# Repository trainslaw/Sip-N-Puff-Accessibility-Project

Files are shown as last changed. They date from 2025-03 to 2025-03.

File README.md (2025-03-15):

# 🧠 Sip-and-Puff Mouse Emulator — Affordable, Open-Source Accessibility Device

## ✨ About the Project

The **Sip-and-Puff Mouse Emulator** is a **low-cost, open-source accessibility device** that allows users who cannot use their hands to control a computer mouse with simple "sip" and "puff" actions, plus an additional bottom lip button for customizeable actions (preset to be middle click for easy scrolling). 

While commercial sip-and-puff systems can cost **upwards of $1,500**, this device is designed to be **DIY-friendly**, **3D printable**, and assembled for **a fraction of the price** — **typically under $85** in materials.

If you or someone you know needs this kind of assistive technology but can't afford commercial versions, **this project is for you**. 

---

## 💡 Features

- **Sip and Puff** for right and left mouse clicks (supports click and drag).
- Optional **joystick module** for directional control (mouse movement).
- **3D printable** housing — fully open-source design.
- **Standard 1/4" tripod mount** on the bottom for flexible positioning (desk mount, wheelchair, etc.).
- Uses **readily available parts** and standard **Arduino Micro**.
- Open-source **Arduino firmware** for customization and improvements.

---

## 📦 Bill of Materials (BOM)

| Component | Quantity | Approx. Cost (USD) |
|---|---|---|
| HiLetgo Digital Barometric Pressure Sensor Module (0-40KPa) | 1 | $3.00 |
| Arduino Micro (or Pro Micro compatible) | 1 | $22.10 |
| Standard joystick module (optional) | 1 | $5.00 |
| M3 x 5mm heat-set threaded inserts | 12 | $8.00 (pack of 50)|
| M3 x 6mm screws | 12 | $6.00 (pack of 100)|
| M2 x 5mm screws | Few | $5.00 (pack of 100)|
| 1/4" threaded insert (tripod mount) | 1 | $1.50 |
| Female-to-female jumper wires | — | $7.00 (pack of 40)|
| 2.5mm ID surgical tubing | ~1 ft | $5.00 |
| PLA filament (3D printing) | ~100g | $20.00 (1kg spool)|

> **Note**: Prices are estimates and may vary depending on supplier and shipping. Total estimated cost: **~$82.60**

---

## 🖨️ 3D Printing

The 3D-printable case is designed to be easily assembled and maintained:
- **Material**: PLA (can use one or multiple colors).
- **Threaded inserts** for strong, durable screw connections.
- **1/4" threaded mount** in base for positioning.

Find STL files in `/3D_Models/printFiles`.

---

## ⚙️ Assembly Guide

🛠️ **Detailed step-by-step assembly instructions** can be found in `/Documentation/Assembly_Guide.md`.  
This includes:
- 3D printing recommendations.
- Sensor, tubing, and electronics installation.
- Wiring diagrams for connecting the Arduino and sensors.
- Firmware upload guide for Arduino Micro.

---

## 💨 How It Works

- **"Puff" action** triggers a left mouse click.
- **"Sip" action** triggers a right mouse click.
- **Bottom Lip Button** triggers a middle click (for easy scrolling).
- **Joystick Functionality** moves the mouse cursor (analog control).

The device uses a **barometric pressure sensor** to detect airflow changes in the attached surgical tubing. Arduino firmware interprets these signals and emulates mouse input via USB.

---

## 🖥️ Usage and Setup

1. **Connect** the device to your computer using a USB cable.
2. **Sip and puff** to generate clicks.
3. Use the **joystick** for cursor movement.
4. **Adjust mount position** as needed for comfort.

---

## 🧑‍💻 Firmware and Customization

The Arduino sketch is available in `/SipNPuff.ino`.  
You can:
- **Adjust pressure thresholds** for sip and puff in the code.
- Modify click/hold behavior.
- Customize joystick sensitivity.

Upload using **Arduino IDE** — instructions included in `/Documentation`.

---

## 🔓 License

This project is licensed under the **Creative Commons Attribution-ShareAlike 4.0 International (CC BY-SA 4.0)**.

> You are free to share, adapt, and build upon this work — even commercially — as long as you **attribute** the original creator and **share alike** under the same license.  
> See the full license [here](https://creativecommons.org/licenses/by-sa/4.0/).

---

## 🤝 Contributing

Contributions are welcome!  
If you improve the design, firmware, or create alternative versions, **please submit a pull request** or open an issue to share your work with the community.

---

## 📣 How to Share and Help

If you build this device or know someone who could benefit from it:
- Share this repo.
- Post about it on social media (tag me if you like! Instagram: @trainslaw24).
- Help improve it for others — **collaboration makes this stronger**.

---

## 📫 Contact

For questions, feedback, or collaboration, feel free to reach out via GitHub issues.

---

## 🔗 Related Links

- [Creative Commons License Info](https://creativecommons.org/licenses/by-sa/4.0/)
- [Instructables Guide (coming soon!)](https://www.instructables.com/)
- [3D Model Repository (Thingiverse Link)](https://www.thingiverse.com/thing:6980375)
- [Testing Video](https://youtu.be/Zvc_8lLqynY)

---

### Created by [trainslaw](https://github.com/trainslaw)

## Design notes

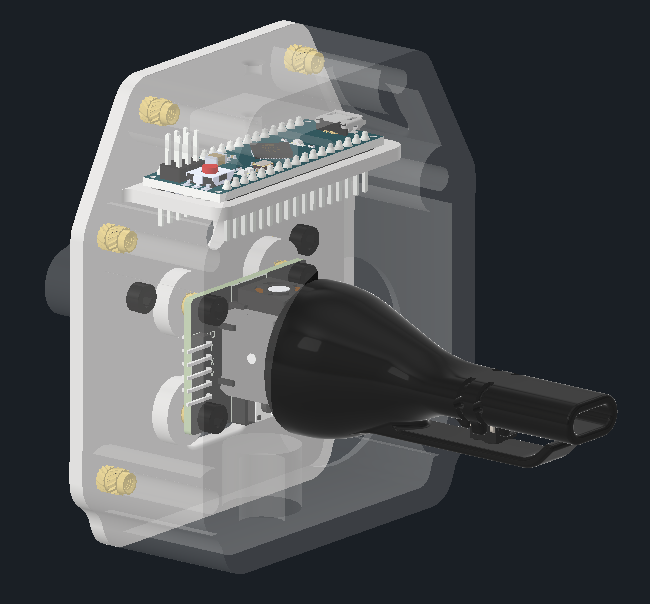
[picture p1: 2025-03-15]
Screenshot 2025-03-14 161028.png

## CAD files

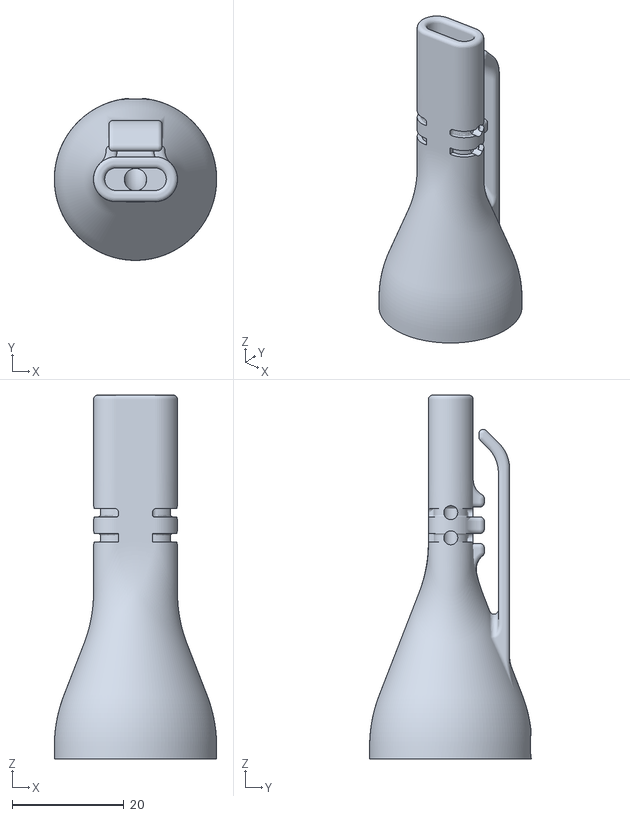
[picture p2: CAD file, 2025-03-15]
3D_Models/Print Files/mouthpiece.stl
29.0 x 28.9 x 65.0

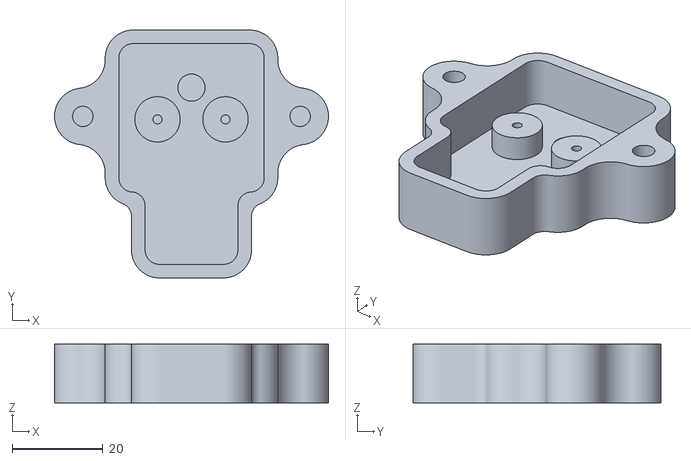
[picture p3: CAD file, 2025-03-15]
3D_Models/Print Files/pressure_housing.stl
60.5 x 54.7 x 13.0

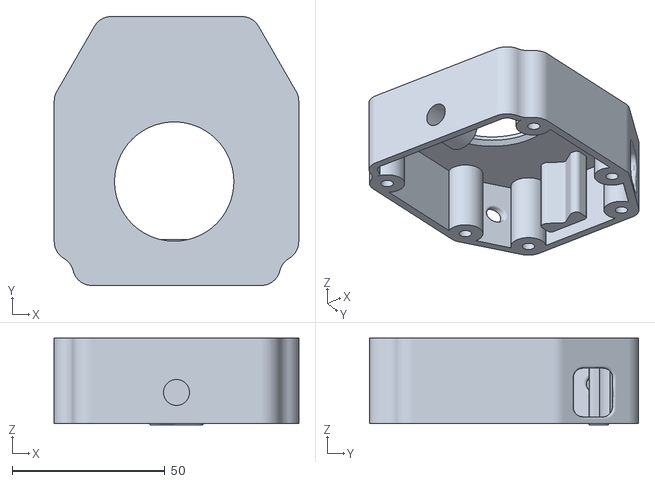
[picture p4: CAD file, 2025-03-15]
3D_Models/Print Files/sip_n_cap.stl
80.0 x 88.0 x 28.4

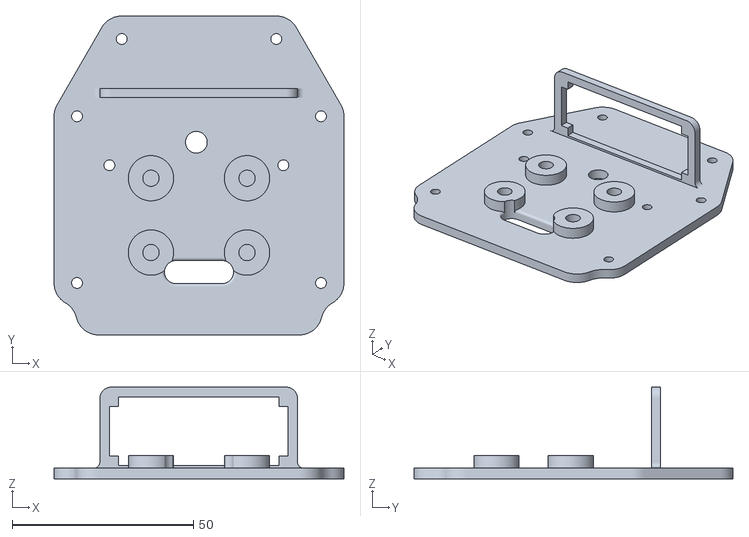
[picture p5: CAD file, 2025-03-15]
3D_Models/Print Files/Sip_n_box.stl
80.0 x 88.0 x 25.3

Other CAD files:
3D_Models/2D-Analog-Thumb-Joystick.iam
3D_Models/2D-Analog-Thumb-Joystick/Baseplate.ipt
3D_Models/2D-Analog-Thumb-Joystick/Case001.ipt
3D_Models/2D-Analog-Thumb-Joystick/Potentiometer_01.ipt
3D_Models/2D-Analog-Thumb-Joystick/Potentiometer_02.ipt
3D_Models/2D-Analog-Thumb-Joystick/Rotator-Unit.ipt
3D_Models/2D-Analog-Thumb-Joystick/Tactile-Switch.ipt
3D_Models/3mm x 6mmL screw.ipt
3D_Models/6X6X4.3_BUTTON.ipt
3D_Models/Base-Board/5x_Ang_Conn.ipt
3D_Models/Base-Board/PCB.ipt
3D_Models/Insert M3 D5 L5mm.ipt
3D_Models/KY-023_Joystick-Module/3D-Analog-Thumb-Joystick.iam
3D_Models/KY-023_Joystick-Module/5x_Ang_Conn.ipt
3D_Models/KY-023_Joystick-Module/BaseBoard.iam
3D_Models/KY-023_Joystick-Module/Baseplate.ipt
3D_Models/KY-023_Joystick-Module/Case.ipt
3D_Models/KY-023_Joystick-Module/OldVersions/3D-Analog-Thumb-Joystick.0001.iam
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

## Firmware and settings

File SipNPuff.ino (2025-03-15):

#include <Mouse.h>
#include <HX711.h>

const int LOADCELL_DOUT_PIN = 2;
const int LOADCELL_SCK_PIN = 3;
HX711 scale;

bool pressure = false;
bool lastPressure = false;
bool vacuum = false;
bool lastVacuum = false;

const int buttonPin = 12;
bool button = false;
bool lastButton = false;

int xPin = A0;
int yPin = A1;

int xVal = 0;
int yVal = 0;

// Timing control
unsigned long lastScaleRead = 0;
unsigned long lastSerialPrint = 0;
unsigned long lastMouseMove = 0;

float weight = 0;

void setup() {
  Serial.begin(9600);
  scale.begin(LOADCELL_DOUT_PIN, LOADCELL_SCK_PIN);
  scale.tare();
  pinMode(buttonPin, INPUT_PULLUP);
}

void loop() {
  unsigned long currentMillis = millis();

  // Read load cell every 35 - 50 ms
  if (currentMillis - lastScaleRead >= 35) {
    weight = scale.get_units(1); // Reduced to 1 unit reading for speed
    lastScaleRead = currentMillis;

    // Update pressure/vacuum status
    pressure = (weight >= 50000);
    vacuum = (weight <= -50000);
  }

  // Read button and joystick
  int buttonState = digitalRead(buttonPin);
  button = (buttonState == LOW);
  xVal = analogRead(xPin);
  yVal = analogRead(yPin);

  // Handle mouse clicks
  if (pressure && !lastPressure) {
    Mouse.press(MOUSE_LEFT);
    lastPressure = true;
  } else if (!pressure && lastPressure) {
    Mouse.release(MOUSE_LEFT);
    lastPressure = false;
  }

  if (vacuum && !lastVacuum) {
    Mouse.click(MOUSE_RIGHT);
    lastVacuum = true;
  } else if (!vacuum && lastVacuum) {
    Mouse.release(MOUSE_RIGHT);
    lastVacuum = false;
  }

  if (button && !lastButton) {
    Mouse.press(MOUSE_MIDDLE);
    lastButton = true;
  } else if (!button && lastButton) {
    Mouse.release(MOUSE_MIDDLE);
    lastButton = false;
  }

  // Handle mouse movement every 5 - 15 ms for smoothness
  if (currentMillis - lastMouseMove >= 2) {
    int xMove = 0;
    int yMove = 0;

    if (xVal > 504) xMove = (1 + 0.05 * (xVal - 504));
    if (xVal < 502) xMove = (-0.05 * (502 - xVal) - 1);
    if (yVal > 500) yMove = (1 + 0.05 * (yVal - 500));
    if (yVal < 498) yMove = (-0.05 * (498 - yVal) - 1);

    Mouse.move(xMove, yMove, 0);
    lastMouseMove = currentMillis;
  }

  // Optional: Serial print every 500 ms for debugging
  //if (currentMillis - lastSerialPrint >= 500) {
    //Serial.print("xValue: "); Serial.println(xVal);
    //Serial.print("yValue: "); Serial.println(yVal);
    //Serial.print("Button: "); Serial.println(button);
    //Serial.print("Pressure: "); Serial.println(pressure);
    //Serial.print("Vacuum: "); Serial.println(vacuum);
    //Serial.println();
    //lastSerialPrint = currentMillis;
  //}
}
